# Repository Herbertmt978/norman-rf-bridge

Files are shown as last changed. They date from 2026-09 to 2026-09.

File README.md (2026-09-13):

# Norman RF Bridge

Control Norman Gen1 shutters from Home Assistant using an ESP32 and a small
2.4 GHz radio. Plug it into USB power and leave it near the shutters. Once
set up, it can send commands directly and repeat learned Norman traffic.

The aim is to replace the Norman hub's control role and its USB repeaters with
hardware you can build, update and use with ESPHome. Direct control and radio
forwarding both work on the prototypes. This is still an experimental project,
not a universal plug-in replacement: setup needs watched learning and some commands
still miss panels. Keep the original controls available while testing.

## What it does

**Control shutters from HA.** The companion
[Norman integration](https://github.com/Herbertmt978/Norman-HA-Integration)
adds individual section and whole-room Open/Close controls. HA sends a Wi-Fi
command to the local ESP; the nRF24-compatible module sends the shutter command.
That path doesn't call the Norman hub or need its password. The integration's
RF transport is currently a pre-release feature; follow its
[RF setup guide](https://github.com/Herbertmt978/Norman-HA-Integration/blob/main/docs/esphome-rf.md).

**Work as a USB-powered repeater.** After learning the installation's commands
and enabling relay mode, the board listens for matching traffic and forwards
it automatically. It can forward commands from the Norman hardware or another
ESP bridge. This runs locally, including when Wi-Fi or HA is unavailable.
It isn't an unrestricted repeater for every packet it hears.

**Learn and manage profiles in HA.** Firmware **0.10.2-experimental** uses a
guided flow in the companion integration. Name a section and room, press the
requested controller actions, and confirm what moved. HA can also learn
forwarding-only actions, rename/regroup profiles, and remove a selected profile
with confirmation. Follow the [setup and profile manual](docs/learning.md).
The learner checks repeated matching samples without assuming the hub's codes
advance in order. It tolerates one-off background messages but refuses to guess
between two plausible targets. A fresh board has learned five sections through
the HA wizard using hub commands, without importing profiles or using an SDR.
All five passed watched individual and whole-bedroom Open/Close-upwards tests
after the ESP was placed in the bedroom. Long-term delivery and use in another
household still need qualification.

**Repeat its own commands.** Firmware **0.10.0-experimental** sends up to two
extra full bursts after a direct command, waiting two seconds after each
successful burst finishes before starting the next.
They use the same command bytes and rolling codes, not three different
commands. Each board has an **RF automatic command repeats** switch in HA.
It starts enabled and remembers your choice. Reboots don't replay old commands.

**Stay useful as an ESPHome device.** The image includes an active Bluetooth
proxy, Wi-Fi signal and uptime diagnostics, radio counters, and OTA updates.
Version **0.11.1-experimental** adds last-command and RF-activity ages, transmitter
faults, learning/profile counts, memory and loop timing, plus a three-second
onboard LED Identify button. See [the diagnostic entity guide](docs/diagnostics.md).
You can add supported sensors on spare pins once power and pin conflicts are
checked. The external radio is for Norman RF; it isn't a Wi-Fi adapter or a
general-purpose packet sniffer.

## Where it fits

```text
HA dashboard or automation
        │ Wi-Fi / ESPHome API
        ▼
ESP32 + nRF24 radio ── Norman RF ──► shutters
        │
        └── another commissioned ESP can repeat matching RF

Norman hub / original repeater ── RF ──► ESP repeater ── RF ──► shutters
```

Putting a directly controlled ESP in a distant room can avoid relying on the
hub's radio reaching that room. HA reaches the ESP over Wi-Fi instead. A board
used only as a repeater still needs to hear the upstream transmitter, so its
placement matters.

In the test installation, the existing sunrise/sunset automation now uses the
office and lounge ESP controls. This was an owner-approved move to experimental
daily use, not a claim that every delivery issue has been solved. HA owns the
schedule; the ESP owns the RF transmission and its bounded extra bursts.
Schedules in the Norman phone app must be disabled separately to avoid competing
commands. Removing the hub also means losing its app-based control and schedules.

## Hardware

The prototypes use the same simple assembly:

| Part | Used here |
| --- | --- |
| ESP32 | [Freenove ESP32 board kit](https://www.amazon.co.uk/dp/B0C9THDPXP), ESP32-WROOM-32E, 4 MiB flash, USB-C |
| Radio | [nRF24L01+ PA/LNA module with SMA antenna](https://www.amazon.co.uk/dp/B0DK2Z6C7K); the photographed chip is marked SI24R1, an nRF24-compatible part |
| Antenna | One attached 2.4 GHz antenna per radio |
| Wiring and power | Jumper leads and USB power; the radio takes 3.3 V from the ESP board in these prototypes |
| Enclosure | [Printable base and top](hardware/enclosure/README.md), supplied as STEP files; the owner has printed them and confirmed the fit |

These are the owner's purchase links, not guarantees about future seller stock.
See [hardware and wiring](docs/wiring.md) for the full GPIO map and power advice.
**Never connect the bare radio to 5 V. Fit its antenna before transmitting.**
The PA/LNA supply has not been qualified for a finished product; a stable
dedicated 3.3 V supply and local decoupling are recommended for further testing.

## Will it work with my shutters?

It is a reasonable candidate for another installation using the same Norman
Gen1 radio protocol. It has not yet been qualified in a second home or across
all Norman motor generations. The Norman name alone isn't enough to establish
compatibility, and the HA integration's support for other hub generations
doesn't mean this radio firmware supports them.

Each motorised section needs its own learned command profile. A shutter with
independent upper and lower sections therefore needs two profiles. The sections
share a radio protocol; they don't each require a completely different decoder.
What changes is the command's identity/selector, its supported operation and its
rolling state. The firmware contains the protocol logic, **not this home's
shutter codes**.

**You shouldn't need a Pluto for a compatible installation.** The ESP/nRF24
receiver can log the supported packets from your existing hub or controller.
The remaining job is to associate captures with the panel and direction you
actually operated, validate them, and save them as that panel's profile. This
is handled by the new [HA learning flow](docs/learning.md). A Pluto or
another suitable SDR is useful if your system uses different radio settings,
the logger sees nothing, or the protocol needs further investigation.

Start with [compatibility and learning your shutters](docs/compatibility.md).
Don't copy someone else's frames or an old full-flash backup of a commissioned
board. Matching the protocol is not the same as learning your installation.

## Getting started

1. Assemble the board using the [verified wiring](docs/wiring.md).
2. Run `scripts/test-protocol.ps1`, then `scripts/build-stage1.ps1` using the
   tested ESPHome version, **2026.4.1**.
3. Flash with `scripts/flash-stage1.ps1 -Port COM3`, replacing COM3 with the
   board's actual port. Provision Wi-Fi through USB/Bluetooth Improv or the
   temporary `Norman RF Bridge Setup` access point.
4. Add the discovered ESPHome device in HA. Confirm the radio reports ready.
5. Add the Norman integration's experimental RF transport, select the bridge
   and follow [guided learning](docs/learning.md) for each section or relay action.
6. Select rooms for direct HA control and test their Open/Close while watching.
   Use Reconfigure later to add, rename, regroup or remove profiles.

A new factory image has no learned commands and cannot move or repeat shutters
until commissioned. Once configured, ordinary USB power is enough; a permanent
USB connection to a computer is not required. HA control needs Wi-Fi, local
repeating does not.

The scripts currently use Windows/PowerShell and put build output under
`D:\CodexBuild\norman-rf-bridge`. `scripts/package-experimental.ps1` packages
factory/OTA binaries, source and an ESP Web Tools manifest with checksums.
This is a developer packaging tool, not a hosted one-click installer.
The separate `*-stage0.ps1` scripts are for the older radio-free recovery image,
not normal RF upgrades.

## What has been tested, and what hasn't

The original two boards have moved their local shutters through HA: five office
sections and four lounge panels, individually and as room groups. Learned repeating has
also been observed, including a Wi-Fi-disconnected test. The original Norman
hardware stayed powered during the recent room trials, so those results don't
prove that every RF path used only ESP devices.

A third, freshly commissioned board learned five bedroom sections through HA.
With upward closing selected, each section passed an individual Close/Open
test, and all five passed two whole-bedroom Close/Open cycles on 13 September
2026. These commands used HA's ESP controls without calling the hub. The existing
hub and repeaters remained powered, so they may still have helped carry RF.
The [learning manual](docs/learning.md#fresh-board-testing-and-remaining-limits)
records the capture fixes, closing-direction correction and test limitations.

An earlier automatic-repeat test closed all four lounge panels, but still left
one of five office sections open. A subsequent Open restored both rooms. An
earlier local transmitter fault also remains unexplained. Extra bursts can
recover some misses; they cannot guarantee reception or fix every fault.

HA shows the requested state after the first successful burst. There is no
motor acknowledgement or measured position, so a green HA action is not proof
that a panel moved. Room controls use interleaved individual commands, not a
native whole-room broadcast, and the motors may start at different times.
There are 32 profile slots per bridge and up to eight sections in one room batch.
Stop, arbitrary percentage positioning and battery feedback aren't implemented.

The current bench image has **no API encryption or OTA authentication** and an
open fallback setup AP. Use it only on a trusted local network. Customer-ready
provisioning, longer reliability tests and product/radio compliance are still
work to do before selling it as a finished replacement.

## More detail

- [Commissioning, repeat settings and recovery](docs/commissioning.md)
- [Compatibility and per-panel learning](docs/compatibility.md)
- [Hardware and GPIO wiring](docs/wiring.md)
- [Enclosure CAD files and checksums](hardware/enclosure/README.md)
- [How the firmware works](docs/product-architecture.md)
- [RF captures, test results and known failures](docs/rf-research.md)

## Credits and licence

This project builds on the Norman research and Arduino examples shared in the
[Home Assistant community thread](https://community.home-assistant.io/t/norman-tdbu-blind-control/705405),
including the `NRF24_Sniff` work and Yveaux's NRF24 Sniffer. It is licensed
under [GPL-3.0-or-later](LICENSE). This is an independent project, not an
official Norman product.

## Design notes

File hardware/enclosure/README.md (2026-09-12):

# Prototype enclosure

Owner-supplied STEP originals, added 12 September 2026:

| Part | File | Size |
| --- | --- | ---: |
| Base | [Print Base Final.step](Print%20Base%20Final.step) | 41,938 bytes |
| Top | [Print Top Final.step](Print%20Top%20Final.step) | 14,423 bytes |

These files are small enough to store directly in Git; Git LFS or external
hosting is not needed. Both are STEP AP214 exports with millimetre geometry
units, exported on 11 September 2026. The originals are retained byte-for-byte.

SHA256 checksums:

```text
9be7ac4f990673bee6f19e478c7d4ce23a979b6654de5eac412a7a8af830f098  Print Base Final.step
4fdfd57ec9b67c29abea7e3dbea5255121f62da969045b637946aaa0161d31f8  Print Top Final.step
```

The owner confirmed on12September2026 that the enclosure has been printed,
fit-tested and works with the prototype hardware. This is owner-confirmed
mechanical fit, not an independent electrical, thermal or product certification.

Import these into a STEP-capable CAD application, inspect the dimensions and
export a mesh supported by your slicer. Printer settings, material and fastening
details have not been recorded here; no STL files are supplied yet. Verify fit
for any hardware or printing variation and check electrical clearances and
thermal performance for the intended installation.

Check fit against the actual [board, radio and wiring](../../docs/wiring.md).
Keep the USB connector accessible and both the ESP32 antenna area and the
external 2.4 GHz antenna clear. Avoid pinching jumper wires or leaving exposed
conductors able to short. Fit the radio antenna before powering a transmit-capable
build. An enclosure is not a substitute for a stable 3.3 V radio supply.

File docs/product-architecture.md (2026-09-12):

# Product architecture

## Current implementation: 0.10.0 experimental

Up to32 explicitly commissioned Gen1 section targets per ESP32. Each has its own
exact templates/counter and preferred close direction; all share one SPI radio
owner and global opt-in relay policy.14 targets across3 rooms are commissioned;
physical whole-house acceptance remains distinct from a successful RF burst.

| Owner | Responsibility |
| --- | --- |
| `protocol/` | 30-byte frames, application CRC, rolling permutation, exact learned-command matching, bounded duplicate cache |
| `LearnedPanel` | One193-byte target record per slot: the compatible95-byte command payload, labels and primary-close direction; migration marker and durable sequence reservation |
| `LearnedRelayEndpoint` | Separate79-byte receive-only command/name record per slot; no outgoing counter or motor membership |
| `match_received_command` | One ambiguity-rejecting classifier across both namespaces; only a panel match may update that panel's observed counter |
| `NormanRFMonitor` | Radio detection/readback, receive FIFO, direct bursts, relay timing, watchdog and radio-fault handling |
| `CommandRepeat` | One volatile last-command cache and shared manual/automatic repeat budget; no counter reservation or persisted command queue |
| `LearningSession` | Explicitly owned, receive-only capture with ambiguity checks, distinct presses and expiry; no standalone transmit or persistence authority |
| Profile management | Identity-checked rename/removal; a reusable tombstone stays within the existing record layout, with no global NVS erase |
| ESPHome YAML | Provisioning, HA API, diagnostics, optional Bluetooth and service actions |
| Norman HA RF adapter | Section and room covers using adopted ESPHome services; one shared serializer, bound target identities, no RF encoding/counter ownership/hub fallback |

## Direct control and repeating are different operations

Direct commands select an explicitly learned open, close-down or optional
close-up template. The ESP reserves the next counter in nonvolatile storage,
updates the two rolling bytes and CRC, then sends 100 copies on channel15 at
55ms spacing. A room batch reserves all selected counters before any RF, then
interleaves up to8 targets in each55ms round. An individual command uses that
same path with one target. A storage failure consumes any earlier reservations
without transmission or rewind. Batch failure makes all selected states uncertain.
This copy count follows the locally successful burst test; the
earlier proposed 1–3-copy limit was not established by measurement.

Version 0.10.0 schedules up to two additional unchanged direct-command bursts,
with a two-second gap after each successful completion, within60seconds of the
original start. Version0.9.2 used20-second start intervals.
The ESPHome automatic-repeat switch persists the opt-out setting, default ON;
it does not persist pending commands. A newer command attempt, observed
conflict, changed profile/counter, disable or radio fault cancels pending work.
An active burst is not interrupted. Manual repeats use the same budget.
HA still returns after the first burst; it doesn't provide another retry loop.
See [repeat policy](commissioning.md#automatic-command-repeats).

Repeating does not generate a counter. While enabled, the receiver scans
channels15 and39 at20ms nominal dwell. An exact learned command received on15
is repeated unchanged on39; a command received on39 is repeated on59, with
20 copies at55ms spacing. Channel59 is terminal. The receive FIFO is drained
before retuning so queued frames retain their channel attribution. A
64-entry/60-second exact-frame cache suppresses echoes, including this unit's
direct commands. Live entries are not evicted to admit new traffic; saturation
fails relay closed. Each bridge forwards an exact frame at most once within
the suppression window, even if it later hears that frame on another channel.
An originating bridge suppresses returning copies of its own direct command.
Thus the path is bounded but does not guarantee both hops occur: placement,
receive timing and which channel is heard first matter. Other channels,
unlearned command families and reply packets are not relayed.

Native room endpoints are explicitly learned in a separate32-slot receive
allowlist, using the same protocol command comparison. Only the newly received
30-byte application frame is forwarded; the saved template is never queued
for replay. Room matching ignores only the two sequence bytes and dependent
CRC, not operation/address/selector bytes. It neither observes nor generates
an individual target counter. Panel inventory protocol3 remains unchanged;
the new relay inventory has its own version1 status action.

Both paths use minimum nRF power, an attached antenna, one half-duplex radio,
TX-completion checking and a bounded watchdog. A successful API response means
the RF burst completed, not that the shutter acknowledged or physically moved.

## Boot, persistence and offline operation

Factory defaults have no learned panel and cannot transmit. Once explicitly
commissioned and relay-enabled, USB power restores the profile and repeat
policy after validation, independently of Wi-Fi/HA. Boot itself sends no command.
The HA relay switch uses `restore_mode: DISABLED`; its presentation must not
overwrite the RF owner's saved enabled state during boot.

Configuration/storage failure blocks transmission. Counter reservation is
durable before a direct burst so a reboot cannot reuse a reserved index. Normal
forward observed counter changes are adopted; ambiguous half-range jumps are
ignored. Community three-code resynchronisation is not enabled. Long outages,
counter wrap/coexistence across real controllers and flash endurance still need
extended qualification.

Slot0 imports the deployed95-byte profile once. A durable migration marker
prevents a missing/corrupt new record reviving stale legacy counters. Existing
commissioned slots may be labelled, but cannot silently change identity or reset
their counter/optional endpoint. Other target slots have independent NVS keys.
Relay-only records use disjoint persistent keys and commissioning markers;
they do not migrate, replace or erase panel records. Default empty, invalid
storage fails closed, and a commissioned endpoint cannot silently change its
command identity. The global relay policy has its own persistent owner. Legacy native actions
address slot0 only. Native protocol3 requires explicit slots, fingerprints and
endpoints for each bounded batch. HA owns room membership and one command lock;
the ESP owns batch reservation and RF scheduling. Repeating needs neither HA nor
Wi-Fi. The unreleased sequential HA sender is replaced, not retained as fallback.

## Product B and A* targets

The connected prototype demonstrates learned individual-command repeating
during Wi-Fi loss. UART records native room Open/Close forwarding, but the
watched trial missed one study section; subsequent direct control moved it.
Native room physical reliability and independent RF attribution remain open.
Version0.9 adds reception of direct hub/ESP channel15 traffic and logs confirm
that first-hop forwarding. Exclusive ESP range extension and reliable delivery
without original repeaters are still unqualified. A dedicated
radio-only Product B image, physical commissioning control,
qualified enclosure and production fixture remain future work. Owner-supplied
STEP enclosure designs are stored under hardware/enclosure; the owner confirms
a printed enclosure fits and works. Broader product qualification is still
pending. It is not yet a universal
Norman replacement that can be sold without installation-specific commissioning.

Product A* adds HA control and diagnostics through ESPHome while keeping the
same local repeat policy. Bluetooth proxy remains active; further sensors can
be added using spare GPIOs after checking power, timing and pin conflicts.
It does not provide arbitrary 2.4GHz or Wi-Fi packet decoding.

## Security and release boundary

The current bench image has no API encryption or OTA authentication and an
open Improv/fallback-AP onboarding path. Keep it on a trusted local network;
do not expose it to the internet or distribute it as a secured customer image.
Customer adoption needs unique API/OTA credentials, protected commissioning,
pinned public packages, signed/versioned updates and a recovery policy.

The local experimental package contains source, factory/OTA binaries and hashes,
not Wi-Fi credentials or learned shutter templates. A factory binary is not a
clone of a commissioned device's NVS. Commission each installation separately.

## Evidence and remaining acceptance work

Direct open/down-close and HA-native control were physically confirmed on one
bedroom lower section. Independent Pluto IQ captures match the transmitted
frames. Relay39→59 was observed with Wi-Fi connected and disconnected; stored
relay enable survives reboot. Upward-close has been correlated and learned;
its separate physical replay result belongs in the investigation evidence log.

Remaining work: whole-house physical acceptance, arbitrary position and stop commands,
all-house range, remote-source variations, congested Wi-Fi/Bluetooth coexistence,
extended power-cycle/soak testing, PA/LNA supply qualification, enclosure and
applicable product/radio compliance. No certification or commercial-readiness
claim is made.

See [commissioning](commissioning.md) and [RF evidence](rf-research.md).

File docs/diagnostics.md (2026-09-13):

# Bridge diagnostics in Home Assistant

Firmware 0.11.1-experimental adds read-only diagnostics to each ESPHome device.
The Norman integration's room and panel controls are unchanged. No new hardware
is needed on the documented Freenove ESP32-WROOM board.

## RF activity

- **RF last direct command** describes the last accepted new direct command,
  its first target and how many additional targets were included. Automatic or
  manual identical repeats do not overwrite it. It is not movement confirmation.
- **RF last direct command age** is seconds since that command started.
- **RF last received age** is seconds since any CRC-valid Norman frame arrived,
  including duplicates and unlearned targets. It does not prove a relay path.
- **RF last relay age** is seconds since a relay burst completed successfully.
- **RF pending repeats** counts remaining scheduled extra bursts, not shutters
  awaiting acknowledgement.
- **RF transmitter fault** reports whether the last completed burst failed.
  A later successful burst clears it. **RF last transmitter fault** retains the
  last failure reason until reboot. Hardware readiness remains a separate entity.

Ages use monotonic uptime, so they do not need internet access or time sync.
They are unknown until the relevant event occurs and reset at reboot. Fault
history also resets; no event history is written to flash. HA can record these
entities if longer history is needed. `complete_not_acknowledged` means the
radio completed its burst, not that the motor acknowledged or moved.

## Learning and capacity

**RF learning active**, **RF learning status** and **RF learning samples** expose
the current guided session without its token or raw frames. Samples mean the
strongest candidate's distinct samples (0–2), not approval to save an ambiguous
capture. The wizard remains the authority for accepting and saving profiles.
Once the capture window expires, the diagnostic reports `capture_expired` even
if an earlier acceptance attempt left a cached error such as `need_two_presses`.
This status-priority correction is the only behavior change from 0.11.0.

Saved panels/free panel slots and saved relay profiles/free relay slots are
reported separately: there are 32 slots in each namespace. Only usable saved
profiles count; a storage fault still needs investigation, not blind replacement.

## Board health and identification

**Free memory**, **Minimum free memory** (since boot) and **Loop time** use the
native ESPHome debug component. Loop time is the longest main-loop interval
observed in the reporting period, not CPU utilisation. Existing Wi-Fi signal,
uptime and reset-reason entities remain available.

**Identify board** flashes the onboard GPIO2 LED six times over three seconds,
then leaves it off. Repeated presses during a sequence do not queue more work.
The sequence uses nonblocking ESPHome delays and does not transmit RF. The LED
may not be visible through an opaque enclosure. This mapping is for the
[Freenove ESP32-WROOM board](https://docs.freenove.com/projects/fnk0090/en/latest/fnk0090/codes/C/1_LED.html);
check other boards before using GPIO2 or connecting anything to it.

These diagnostics do not alter RF timings, rolling codes, profile storage,
repeater policy or shutter automations. Keep health polling moderate: the RF
task and existing Bluetooth proxy share a small microcontroller.

## Verification

On 13 September 2026, this build was installed by OTA on three Freenove bridges.
All saved panel identities, names, closing directions and rolling counters
survived the update. HA discovered the new entities and reported the expected
profile counts. A temporary learning session showed active/capturing status,
then returned to idle after cancellation without saving a profile. Identify was
accepted through HA and the radio transmit count stayed unchanged; the LED
itself was not observed through the enclosure.

The 0.11.1 expiry correction was also checked on a real bridge: an empty capture
produced `need_two_presses`, the diagnostic changed to `capture_expired` after
the 60-second window, and cancellation returned it to `idle`. No profile was
saved. Native regression tests cover the expiry boundary with a cached error.

Seven native CTest suites, seven Python tool tests and the pinned ESPHome
2026.4.1 build passed. No shutters were moved for this diagnostics update and no
transmitter fault was deliberately induced. These checks do not extend the
existing RF delivery or whole-house reliability claims.

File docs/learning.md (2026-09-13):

# Set up and manage your shutters in Home Assistant

Use bridge firmware **0.10.2-experimental** with the matching Norman integration
update for this flow. Version 0.10.0 introduced learning but has the hub-capture
limitations described below. Older bridges keep the existing manual
commissioning route. This is for the supported Norman Gen1 RF protocol; a
second household has not yet been qualified. A Pluto SDR is not required when
your controller uses the supported radio settings.

## Install and connect

Fit the radio antenna before powering the board. Follow the [wiring guide](wiring.md),
install the firmware, provision Wi-Fi and add the discovered device to HA's
ESPHome integration. Keep your existing Norman controller working.

Install the matching **Norman 0.5.0b2 candidate** from the
[integration's main branch](https://github.com/Herbertmt978/Norman-HA-Integration/tree/main).
[PR18](https://github.com/Herbertmt978/Norman-HA-Integration/pull/18)
was merged on 12 September 2026. As of 13 September, the normal HACS release is
still v0.4.1 and does not contain this flow.
For a manual candidate install, back up your existing integration folder, copy
main's `custom_components/norman_gen1` directory into HA's
`config/custom_components/norman_gen1`, and restart HA. A subsequent HACS update
can replace a manual candidate, so check the installed version before learning.

In Settings → Devices & services → Add integration, choose Norman, then
**ESPHome RF bridge**. Select the adopted bridge. The profile-management menu
appears even when the board has not learned anything yet.

For a bridge already configured in Norman, use its **Reconfigure** menu. You
do not need ESPHome YAML, packet logs or a terminal for these steps.

## Add a panel

Count independently controlled motors, not window frames. A shutter with
separate upper and lower sections needs two profiles.

1. Choose **Add a motorised section**. Give it a name and room, such as
   `Bottom left` and `Office`. Choose the closing direction you want HA Close
   to use, and whether to learn the opposite closing direction too. Choose
   **Upwards** if that is your blackout position; do not teach a downward
   close while the wizard asks for upward close.
2. Let earlier movements and repeats finish before starting. When the page says
   **Open**, press that individual section's Open action
   twice on the same original controller, at least eight seconds apart. Check
   that the intended section moves, then select Continue within one minute.
3. Follow the Close prompt in the same way. Do not switch between a physical
   remote and the app/hub during a learning session. Their messages may belong
   to different command families. Do not press whole-room controls here.
4. Confirm the physical target and actions, then save. The bridge stores the
   validated templates and current rolling state. Saving itself sends no RF.
5. Add the remaining sections, then choose **Finish: select rooms for HA**.
   Each selected room gets Open/Close, alongside each individual section.
6. Watch the shutters while testing their new HA controls. Successful packet
   transmission is not confirmation of movement. Restore their starting state.

The controller can be the Norman app/hub, a physical remote, or an existing HA
hub control that sends the requested action. Check the actual closing direction:
HA's existing Close button may be configured for the opposite endpoint. A slider
at 100% normally means Open in HA, not the Norman protocol's upward-close value.
Use the Norman app when the existing HA control cannot send the required direction.

For learning, put the ESP where it receives the controller clearly, initially
near the hub if necessary. After saving, move it near the shutters for direct
control and test again. HA reaches it over Wi-Fi; the hub does not have to reach
that room for direct ESP commands. Repeating is different: a relay still has to
hear the upstream radio. A failed distant-room movement is not, by itself,
evidence that learning failed.

Each capture requires two distinct, matching samples at least eight seconds
apart, not repeated copies of one radio burst. Version 0.10.2 remembers sample
codes heard in the first burst so their later echoes cannot count again. It
does not require the hub's decoded codes to advance within a particular range.
The final sample supplies the initial rolling state; this is not a new universal
rolling-code rule or a change to normal transmit-counter handling.

Open establishes the target/controller identity. The bridge keeps up to eight
action candidates and accepts only one with two matching samples. A one-off
message for another target does not spoil the capture. Two qualifying candidates,
conflicting actions for the selected target, or too much distinct traffic cause
rejection rather than a guess. Candidate evidence freezes after its second
sample, but the bridge keeps checking for competing candidates until Continue.
Close then listens only for the accepted Open identity: traffic for another
target supplies no evidence. For a rejected capture, choose Retry and use only
the requested action. A capture lasts one minute and the whole
session expires after ten minutes. Cancel discards unsaved captures. Existing
profiles are never overwritten by learning a duplicate.

While learning, this bridge's direct transmissions, automatic repeats and relay
transmissions pause. Its saved relay/repeat preferences do not change. Other
bridges and Norman hardware continue operating. Reboot discards the learning
session; completed profiles survive. Radio reception must reach the learning
bridge, so initially place it near the original controller.

### Fresh-board testing and remaining limits

On 13 September 2026, a new board was installed and added through HA with no
copied profiles. Teaching it with individual commands from the existing hub
did not complete reliably: capture windows also heard a different valid packet
family, including delayed traffic. Moving the board beside the hub allowed one
Open capture, but did not eliminate the problem. In a separate Close window,
two distinct same-action frames did not satisfy the learner's forward rolling
index check. A later quiet-window retry reached confirmation, but the unsaved
trial was discarded rather than treated as a reliable onboarding pass.

An initial 0.10.1 candidate still rejected background traffic arriving between
the two Open commands. Version 0.10.2 uses the bounded candidate rules above.
Synthetic regression tests cover the observed code jump, background traffic in
either order, competing targets, multi-code burst echoes, wrong panels, conflicting
actions, capacity limits and expiration.

With 0.10.2, all five bedroom sections were saved through the actual HA wizard
using hub commands: all ten Open/Close capture steps completed without retries.
No profiles were imported and no SDR was needed for that learning pass. The five
profiles survived a power cycle and created individual covers plus a room cover.
Some direct movements were unclear from the camera while the ESP was still
beside the distant hub. It was then moved into the bedroom for direct control.

The owner wanted upward closing for blackout. All five profiles were removed
and relearned through the wizard with Upwards selected, using the hub's Open
and upward-close actions. Two capture windows expired while checking the first
replacement; confirming promptly completed it. The other four replacements
accepted both actions on their first capture attempts. This distinction matters:
the ten-step, no-retry result above was the initial downward-close learning pass.

All five upward-close profiles then passed watched individual ESP Close/Open
tests, followed by a second successful whole-bedroom Close/Open cycle. Across
the two room cycles, all five sections closed upwards and reopened; no extra
manual command retry was needed. The final state was open. HA called only the
ESP covers for these movement tests, with the configured two automatic repeats.
The original hub and repeaters remained powered, so this proves direct command
generation without a hub API call, not an exclusively ESP radio path. HA still
has no motor feedback, and these short watched tests do not establish unattended
or whole-house reliability.

This is a fresh-device test in the same installation, not universal hub
compatibility or a qualified second household. Keep the original controller
available and cancel if the intended action cannot be identified consistently.

## Add a repeater action

Choose **Add an action for repeating**. Name a single action, such as `Office
Open`, and press it twice when prompted. Confirm and save it. Repeat separately
for Close and other required actions. You can learn native room actions this
way without pretending that their direct-generation rolling rules are known.

Enable autonomous repeating on confirmation, or later with the ESPHome device's
**RF autonomous relay** switch. A relay-only profile does not create an HA cover.
It forwards fresh matching frames unchanged, locally, even without HA or Wi-Fi.
Use **Finish without direct controls** for a repeater-only bridge.

## Rename, move or remove a profile

Open Norman → Reconfigure → select the bridge → **Rename, regroup or remove a
saved profile**. Choose the named panel or relay action.

Renaming or changing a room keeps the RF identity and rolling state. Existing
HA bindings refresh. Each directly controlled room currently supports up to
eight motorised sections. Changing a room name can change the room entity;
check automations referring to it.

The current edit screen changes names and rooms, not learned endpoints or the
preferred closing direction. To change direction, remove that profile and learn
it again with the desired direction selected. Do this one section at a time;
confirm the replacement works before removing the next. There is no one-click
undo, and references to the previous HA cover may need updating.

Removal requires a separate unchecked confirmation. It affects only that
profile on that bridge. A removed panel loses its bound HA cover, and its room
cover disappears if no bound sections remain. Other bridges, the original hub
and original controllers are not unpaired or erased. Update automations that
used the removed entities. The freed slot can be learned again; recovery is
relearning, not an undo button. Removing a profile from one repeater does not
remove copies from other repeaters.

## Position sliders and delivery limits

Open/Close are supported. The optional opposite endpoint is retained on the
bridge. A continuous percentage slider is not offered: the current encoder
only sends learned endpoints, not arbitrary verified positions. A captured Open
value of 37 is a protocol setting, not a measured 37% opening. A future position
feature needs validated intermediate-position commands; timed movement would
be an estimate and would need a verified Stop command too.

Automatic direct repeats keep the full 100-copy burst, wait two seconds after
successful completion, then repeat it, up to two extra bursts. Frames and
rolling codes are unchanged. New/conflicting commands, disable, faults and
reboot cancel pending repeats; work also expires after 60 seconds. The radio
cannot listen while transmitting. More bursts improve the chance of reception
but do not guarantee that every section moves.

Assign each panel one direct-command bridge. Other bridges can repeat its
traffic; they should not independently generate competing rolling sequences.
Keep schedules in the Norman app separate from HA automations to avoid
conflicting commands.

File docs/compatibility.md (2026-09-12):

# Will it work in another home?

The reusable part is the firmware and radio protocol. The installation-specific
part is the set of commands for your shutters. You can flash the same factory
image onto another board, but it won't arrive knowing which motors to control.

So far, two ESP32/nRF24-compatible boards have been tested in one Norman Gen1
installation. Community work provides further evidence for this protocol family,
but not a compatibility guarantee for every Norman product. A second household
test is still needed before describing setup as generally proven.

## Does each panel use different RF?

Each independently controlled section needs a separate profile. The tested
upper/lower shutter arrangement has more motorised sections than physical
window frames, so count the motors you can control, not just the windows.

The observed sections use the same packet format and radio settings. Their
messages contain different identities/selectors and operations, plus rolling
fields that change between commands. This firmware stores the exact learned
Open and preferred Close templates for each section, with an optional opposite
closing direction. It also stores the sequence needed for the next direct command.

The code understands that format; it doesn't guess another home's addresses.
The capture-to-profile process also establishes which physical panel a command
controls. Neither an RF number nor a label imported from a hub proves where the
panel is mounted.

## Do I need a Pluto SDR?

Not as a normal part of operating the bridge. For the supported radio settings,
the nRF24 receiver can capture decoded packets itself, even before any shutter
profiles have been commissioned. Its private Wi-Fi log includes channel numbers
and payloads marked `RX valid` when the application frame passes validation.

The current receiver uses the community sketch's five-byte radio address,
1 Mbps operation and candidate channels 15, 39 and 59. These are built into the
driver; it isn't a general scanner for unknown addresses or modulation. With
relay enabled it concentrates on channels 15 and 39. A new, uncommissioned unit
does not transmit simply because it heard something.

A Pluto was used here to investigate radio settings and independently compare
transmissions. That research is reusable. You don't need to repeat the entire
SDR investigation for every panel if your packets match the supported format.
If they don't, an SDR may help determine why; buying one is not the first setup
step. No captured packets could also mean poor reception, wiring, power, channel
timing or a different controller source, rather than incompatible shutters.

## Guided setup in Home Assistant

Firmware0.10.0 and the matching Norman integration provide a [guided learning
and profile-management flow](learning.md). It captures actions on the ESP,
requires physical confirmation and creates named panel/room controls. It also
supports relay-only actions and explicit removal. The flow does not decode
unknown radio protocols or infer room membership without user input.

## Advanced manual commissioning

1. Keep a working original controller available. Place the ESP/radio near it,
   with the antenna fitted and reliable power. Leave relay disabled while
   identifying captures.
2. Use the [bounded passive logger](commissioning.md#passive-wi-fi-logs).
   Operate one section and one direction at a time, noting the time and movement.
   Capture Open, the preferred Close direction and any other supported endpoint.
   Keep the source consistent: don't mix an app/hub capture with a different
   remote's frames and assume they belong to the same command family.
3. Validate the frames and their relationship. The log carries a 32-byte radio
   payload; this protocol uses the first 30 bytes as the application frame.
   The last two bytes are padding in the tested implementation. The command-line
   commissioning actions take 60 hex characters for the application frame.
4. Establish the current rolling index using the protocol decoder, not a guessed
   number or a copied value from another home. The byte-25 permutation and
   validation code live in `protocol/`; the hub's two rolling bytes are not
   simply interchangeable. The guided flow handles this for supported captures.
5. Save the panel with `commission-target`, using a stable slot, physical name,
   room, templates and current index. Read `targets` back to check the identity
   and supported endpoints. See the [command reference](commissioning.md#explicit-per-installation-learning).
6. Test that panel in both directions under observation and restore its starting
   state. Only then add more panels and use the integration's room controls.

This advanced route still needs somebody comfortable with logs and command-line
tools. Most supported installations should start with the HA wizard instead.
Neither route automatically authorizes every shutter in radio range.

## Repeating versus replacing the hub

For **repeating**, learn the command families the board is allowed to forward,
then enable its autonomous relay. It forwards a newly heard matching command
without inventing a fresh rolling code. Native room commands need separate
relay-only entries; learning individual sections doesn't automatically permit
every room operation.

For **direct HA control**, learn each motorised section and assign each room to
one direct-command bridge. HA sends Open/Close to that bridge, which creates
the next valid learned command. It can replace the hub's role in those HA
actions without needing the hub reachable over RF. The current whole-room
control is an interleaved batch of individual section commands, not a generated
native room packet.

Use other bridges to repeat those frames, not to independently generate commands
for the same profiles. They could otherwise compete over rolling state. The HA
adapter prevents duplicate direct bindings within one HA instance, but it can't
coordinate independent HA instances or manual native actions elsewhere.

The original hub and app can remain available. Their schedules are not disabled
by adding this integration, and their displayed positions may be stale after
an ESP command. Keep competing schedules off during testing. Long-term
coexistence and missed-command recovery remain areas for further testing.

## Sharing a build

Share the firmware, wiring and enclosure files. Don't share commissioned full
flash images, household captures or saved rolling state. Each installation
needs its own learning and checks, and the current unauthenticated bench image
needs better provisioning before it is suitable for sale.

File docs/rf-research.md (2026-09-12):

# Evidence and current limits

## Camera-observed qualification and ESP-to-ESP forwarding — 12 September 2026

Both prototypes have antennas, USB power and native ESPHome connectivity. One
is positioned by the downstairs hub and one in the office; an unplug/reconnect
test confirmed the mapping. Cameras provide independent
physical observations for the four lounge panels and five motorised office
sections. Home Assistant's assumed state is not used as a movement result.

The leftmost lounge panel closed and reopened through the hub, with the first
bridge logging both unchanged39-to59 relay bursts on0.8. It also closed and
reopened via direct HA-to-ESP commands while both ESP relay policies were off.
Original repeaters remained powered: this proves hub-independent command
generation, not original-repeater-free delivery. All lounge panels were
restored open after these tests.

The old enabled relay listened only on39 while direct ESP commands transmit
on15. Version0.9 adds scanning of15/39 with bounded15-to39 and39-to59 routing,
retaining exact learned allowlists and duplicate suppression. Host route/cache
tests and the pinned ESPHome build pass. Both units retained commissioned
profiles across OTA. The updated first unit logged hub-originated15-to39
forwarding and the lounge pilot still closed/reopened through the hub.

The second unit then sent100 copies of an office Top Left command on15. The
first unit received the matching CRC-valid frame and logged20 unchanged copies
on39. This is positive ESP-to-ESP forwarding evidence, but the office shutter
stayed open. A first-bridge direct Bottom Left test also left that section open.
These initial failures were followed by successful local tests described below;
range, receive-channel availability and counter acceptance are not yet isolated
as causes. A logged relay burst alone is not proof of shutter movement.

All five office motorised sections subsequently passed individual direct
close/open pairs from the office ESP. The whole-office batch closed all five
at11:56:15UTC and reopened all five at11:56:39UTC. The motorless top-right section
is excluded. All four lounge panels also passed individual direct close/open
pairs from the downstairs ESP; the four-panel batch closed all four
at12:01:05UTC and reopened all four at12:01:23UTC. Both rooms were restored open.
The scheduler was unchanged: these room actions interleave learned individual
commands, not a synthesized native-room packet. Camera snapshots confirm end
positions, not exact or simultaneous motor start times.

Two initial office commands failed before a hub close followed by successful
direct open/close/open sequences. Only one of those targets adopted a newer
observed rolling index; another succeeded without adopting the observed index.
This does not establish a universal stale-counter diagnosis or justify automatic
resynchronisation. No counter reset or speculative retry was added.

Direct test pairs called only ESPHome actions, not Norman hub services.
Original hub/repeaters were still powered and could have forwarded those
signals. Each room has one successful combined close/open pass at this
placement, not an isolated ESP-only or long-term reliability qualification.
The owner is retaining the hub and original repeaters for normal operation;
exclusive RF-path isolation is deferred rather than reported as a pass.

Four bounded30-second R1 Pluto recordings captured their intended command
windows but decoded no valid Norman frames. The sample-rate and LO readbacks
were correct. These captures do not independently corroborate RF transmission;
the stronger current evidence is matching frames in the other ESP's receiver
log. The Pluto is upstairs in another office, and its new antenna bands are
not independently identified. All Pluto work remains receive-only.

Native room generation, prolonged room reliability and original-repeater-free
range tests remain separate qualification items. Historical results below retain their
original firmware and placement boundaries.

## Native room receive-only support — 0.8

Three consecutive owner-triggered native study Open requests were captured on
channel39 with valid CRC. They retained the native operation/selector body but
did not follow an increment-by-one sequence under the community byte25 decoder.
Do not infer or generate a room counter from that model. The old0.7.1 firmware
received all three without forwarding because none matched an individual target.

The0.8 build introduces explicitly commissioned receive-only endpoints. It
passes the freshly received application frame unchanged to the existing relay,
without synthesizing either sequence byte. All14 direct target records and
their counters were preserved across OTA; two native study endpoints survive
a subsequent reboot with zero startup transmission. Host tests cover all65,536
sequence-byte pairs, invalid frames, ambiguity, storage failures and counter
isolation.

In the first watched 0.8 native-room close/open trial, UART recorded each fresh
channel39 command matching its separate relay-only endpoint and completing
20 copies on59. No individual target counter changed. The owner reported that
Top Left did not move; the trial is not a full-room physical pass. Subsequent
HA→ESP direct close/open commands moved that section, with ten matching
CRC-valid close frames independently decoded on Pluto channel15.

The native-room Pluto recording ended before the app commands were sent.
Its zero decoded packets are a missed recording window, not evidence of absent
RF. UART completion is firmware evidence, not independent antenna-output
verification. Original repeaters remained powered, so a successful movement
cannot yet be attributed solely to this bridge. Signal, timing and receiver
acceptance remain hypotheses for the miss, not established causes.

A fixed-placement individual Top Left comparison subsequently succeeded for
hub Close/Open with ESP relay disabled. With relay enabled, UART recorded
Close/Open39→59 forwarding,20copies each; the owner confirmed both movements
and all five study sections restored open. Other repeaters
remained powered. The successful disabled baseline means this comparison
cannot establish added range or exclusive ESP contribution.

In a later trial the owner found one original repeater still powered, so the
initial supposed isolation and failed Close are not all-repeaters-off evidence.
After correcting this, clean hub Close/Open with the ESP relay enabled both
physically succeeded while all originals were reported unplugged. UART recorded
20 forwarded copies per command. A matching ESP-disabled Close was then received
on59 with no ESP transmission during the recorded window; the owner reported
that it also closed. This therefore does not establish a range benefit.
A later status read found one additional unrecorded relay burst after the
window ended; do not infer its source or extend the zero-TX interval. Reception
channel alone does not identify the emitter, and a hopping receiver's missing
channel record is not proof of absent RF. This is not yet an extra-range claim.

The subsequent restoration exposed another physical failure: a hub Open with
original repeaters absent did not reopen Top Left, and a later direct ESP Open
also left it closed despite completing100copies/channel15. The originals were
restored by the owner; one normal-hub restoration Open was then issued. This
does not establish whether the miss is range, timing, counter acceptance or
another cause. Do not promote successful TX into reliable movement or reset
rolling state as a speculative recovery.

The production HA study room cover currently reports `level_fanout` for Open
and Close. It is not an equivalent source for an app-native room comparison.
Its existing setting and production integration have not been changed.

## Existing Home Assistant integration

The existing
[`Herbertmt978/Norman-HA-Integration`](https://github.com/Herbertmt978/Norman-HA-Integration)
retains its HTTP hub transport. The experimental RF branch adds a separate
ESPHome-backed cover without moving packet encoding or counter ownership into HA.

## RF evidence

- The Norman HUB01 FCC test report records proprietary 1 Mbps GFSK at 2415,
  2439, and 2459 MHz (nRF channels 15, 39, and 59):
  <https://fcc.report/FCC-ID/PPQ-HUB01/4063103.pdf>.
- The RPT01 filing covers 2415–2459 MHz:
  <https://fccid.io/PPQ-RPT01>.
- Home Assistant community post 58, dated 9 August 2026, provides a working
  Arduino/nRF24L01+ capture-and-replay proof of concept:
  <https://community.home-assistant.io/t/norman-tdbu-blind-control/705405/58>.
- That proof of concept derives from the GPL NRF24 Sniffer:
  <https://github.com/Yveaux/NRF24_Sniffer>.

The reported channel-15 parameters are 1 Mbps, five-byte address
`dc:5c:9c:1c:05`, nRF hardware CRC disabled, and Norman application CRC-16
polynomial `0x0083` with initial value `0xacc8`. The sketch handles a 30-byte
application frame, but its payload-size call is commented out; with the RF24
library's static default it may actually put 32 bytes on air, ending in two
zero pad bytes. Receive-only firmware must retain all 32 bytes until captures
from this installation settle the on-air width.

The shared sketch is not a transparent repeater: it embeds one author's
captured open/close templates, learns/advances a rolling value, and transmits a
100-copy burst. Its AVR pin names, `fdevopen`, ISR behaviour, and device-specific
payloads are not suitable for direct ESP32 deployment.

## What other 2.4 GHz equipment can see

- A stock CC2652P SLZB-06 is a Zigbee/Thread coordinator. Its exposed firmware
  and serial/network protocols do not offer arbitrary proprietary-GFSK capture
  or transmit, and Zigbee's IEEE 802.15.4 PHY does not decode Nordic Enhanced
  ShockBurst. The CC2652P silicon has a flexible proprietary radio mode, but
  using it for Norman would require replacement TI firmware and would take the
  adapter out of ZHA service; this is not a safe experiment on the live
  coordinator.
- UniFi radio capture and Wireshark monitor mode decode IEEE 802.11 frames.
  UniFi can correlate the Norman hub's HTTP calls or show aggregate RF energy,
  but it cannot recover Norman/nRF24 payloads.
- The purchased nRF24L01+ is the appropriate targeted receiver after channel,
  data rate, and address are known. A HackRF-class SDR plus GNU Radio/gr-nordic
  is the better discovery tool when those parameters are unknown.

## Unknowns to resolve on the user's installation

- whether the five-byte address is universal;
- whether the radio payload is 30 bytes or 32 bytes with two pad bytes;
- which channels the Gen 1 plantation shutters use in practice;
- the user's remote/room/panel selectors and command bytes;
- genuine RPT01 forwarding timing, cross-channel behaviour, and loop control;
- whether one half-duplex nRF24L01+ provides adequate relay timing;
- safe rolling-state behaviour across reboot and missed traffic.

## Local RF investigation — 10 September 2026

All 58 posts in the linked community discussion were read, including post39's
no-ACK/repeated-burst observation and the complete post58 Arduino sketch. The
256-entry permutation and reported three-sequential-command resynchronisation
are community findings; resynchronisation is not yet locally proven.

The initial monitor wrote RX_ADDR_P0 in the wrong order. RF24's uint64_t overload
for `0xdc5c9c1c05` writes register bytes `05 1c 9c 5c dc` (least-significant
first). Correcting this produced the first CRC-valid local reception. The
subsequent diagnostic fix drains FIFO occupancy rather than relying on the
cleared RX_DR event and compares only the first 30 bytes for duplicates. The two
extra captured bytes vary and must not be part of application identity.

A Pluto-compatible device identifies as Rev.C Z7010/AD9361. Its R1 connector has
the owner's 2.4 GHz antenna; R2/T1/T2 are unconnected. Receive-only captures use
R1/A_BALANCED, 4 Msps, 3.2 MHz RF bandwidth, manual gain30 dB and int16 I/Q
containers containing signed12-bit samples. The official ADI Windows drivers
were installed manually by the owner; IIO and RNDIS then reported OK.

Independent offline GFSK demodulation at1 Mbps recovered50 CRC-valid copies of
one hub open frame at2415 MHz. Its30 application bytes matched the ESP32 capture
on channel59 exactly. A separate12-second192 MB USB capture recovered73
CRC-valid copies of the corresponding close command, matching the ESP32's
channel39 capture. Open versus close changes application byte4 (`38` versus
`f8`) for this particular hub/panel command, in addition to rolling bytes24/25
and CRC28/29. These are learned installation-specific templates, not universal
open/close opcodes or proof of physical position.

Raw IQ, private templates, command timestamps and hashes are retained outside
Git under `D:/CodexTemp/norman-rf-investigation-20260910`. The first command IQ
recording is explicitly a13.305344-second prefix: native `/tmp` filled before
the requested15 seconds. That prefix transferred with a matching SHA256; it is
usable for frame decoding, not complete-burst counting. Normal host-streamed
captures avoid the native `/tmp` limit and check exact sample count.

`scripts/decode-iq.py` searches clock phase and polarity, accepts only the known
application length and CRC, and does no bit repair. Three deterministic
synthetic waveform/CRC tests and a real idle recording support its validation;
the idle recording contained no CRC-valid Norman frames. The historical0.4
transmit action was bounded to supported channels, valid30-byte frames,1–100
copies,55 ms spacing, lowest nRF power and a10-second cooldown. It is neither
an autonomous repeater nor a sellable release. The current0.5 learned-command
API replaces that raw bench action; see the measurements below.

## Learned commands and autonomous relay — 0.5

The owner physically confirmed native HA→ESPHome→RF close-down/open after reboot.
The profile/counter survive reboot; the relay switch was corrected to stop its
default boot action overwriting the RF owner's saved enabled state.

Independent Pluto reception found84 copies on channel39 while ESP sent only on15.
With the nearby original repeater unplugged, the comparable test decoded zero
on39. The owner restored that repeater; two other repeaters and the hub remained
on throughout, so this does not isolate every path in the house.

For one exact learned command, ESP UART recorded RX39 followed by20 unchanged
TX59 copies and duplicate suppression. A corresponding Pluto59 recording decoded
82 valid copies; other repeaters also transmit there, so not all82 are attributed
to ESP. A second UART test recorded the same relay while Wi-Fi was disabled.
The initial Wi-Fi test did not promptly reconnect; local recovery was then moved
to a script with a bounded restart if reconnection fails. Recovery requalification
is separate from the already observed offline RF operation.

The owner's isolated lower-left upward-close capture decoded61 identical valid
frames. It retains the learned target body but changes bytes2/3 versus close-down,
not byte4 alone. Firmware now accepts only exact saved endpoint bodies, excluding
rolling fields and CRC, instead of treating one byte as a universal command.
The other lower panel differed in the retained target body and is not admitted.

Application counters and the physical effect of newly generated direct commands
are proven for this pilot, not arbitrary controller co-existence over256 cycles.
The 30-byte application identity is established; transmitting32 static bytes
with two zero pads works locally, but this is not a complete on-air format proof
for every Norman product.

## Native room selector investigation — 10 September 2026

Offline comparison of one owner's whole-room open/close pair with five watched
section identities found a consistent selector relationship: reversing the bits
of `section_byte21 XOR room_byte21` gives the section's HA group ID. All five
groups matched the independently read HA metadata. Apart from command and
sequence fields, these frames differ only at byte21. This is evidence for this
room's selector encoding, not a universal address constant, physical membership
guarantee or permission to synthesize arbitrary group commands.

The native room operation also has different command fields from individual
position commands. It must not be implemented by changing only the selector in
an individual template. The captured native pair passes the existing CRC checks,
but its two decoded sequence values were observed about five minutes apart.
They do not establish a next-code rule or independent room-counter ownership.

The [community Arduino sample](https://community.home-assistant.io/t/norman-tdbu-blind-control/705405/58)
uses a byte25 lookup to update one in-memory sequence and generates the next
value for its captured commands. That is not evidence of safe simultaneous
multi-target sequencing or shared hub/remote coexistence on this installation.
Original hub samples do not consistently have byte24 equal to decoded byte25;
do not mistake our generated-frame convention for the original hub's format.

Before 0.8, native room selectors matched none of the14 individual profiles,
so those commands were received but not forwarded. Version0.8 closes that
eligibility gap with separate receive-only endpoints, as described above;
it does not establish a cause or remedy for every missed physical movement.
No generated native-room direct command or room counter has been introduced.

## Later HA room checks and identical repeats — 12 September 2026

The production HA RF candidate exposed nine physically mapped section covers
and two room covers. Separate room close/open checks passed again, but subsequent
combined and sequential-room runs missed sections. In the sequential run, with
a five-second gap after the office burst, HA completed both actions while the
cameras showed office4/5 and lounge2/4 closed. Open restored the lounge but left
two office sections closed; individual Opens restored them. The schedule was
not migrated or enabled. The HA position is still an assumed command intent.

At the owner's request,0.9.1 adds explicit repeats of the most recent completed
local command. These are separate100-copy bursts using the original frames,
not repeated new rolling-code reservations. Maximum two additional bursts
within60seconds, exact request matching, volatile storage and invalidation
rules are documented in [commissioning](commissioning.md#explicit-identical-command-repeat).
Default sending and autonomous relay policy are unchanged.

Both prototypes received0.9.1; all14 identities/endpoints were retained. Office
rolling counters were identical across its update; downstairs office counters
advanced while it received the ongoing office test, with no reset. Five host
CTest suites, three decoder tests, four logger tests and the pinned ESPHome
build passed. Fresh boot rejected repeat without a prior local command.

Camera-observed comparison:

| Trial | Original burst | Later identical burst(s) | Restoration |
| --- | --- | --- | --- |
| Office Close | Four of five closed; Top Left remained open | First repeat still4/5; second repeat5/5 | New Open reopened5/5; an extra identical Open did not reverse them |
| Office second pair | Close5/5 on first burst | One identical Close retained5/5 | Open5/5 on first burst |
| Lounge Close | Three of four closed; third from camera-left stayed open | First identical repeat4/4; second retained4/4 | New Open reopened4/4 |

Originals and repeats were about20seconds apart in these manual comparisons.
The office log recorded500,1000,1500 total transmitted copies across its first
Close and two repeats. Native counter readback showed only the original
reservation. A further repeat request was refused. Lounge repeats likewise
left the four command counters unchanged. These results demonstrate recovery
from specific misses, not a generally validated automatic retry cadence.

During the first office comparison, the downstairs bridge, still running0.9,
logged `radio_tx_failed` partway through a channel39 relay. The latched fault
disabled autonomous repeating. Its subsequent0.9.1 OTA/reboot restored the
saved enabled policy. The existing diagnostic does not distinguish a timing,
SPI, supply or radio fault; no root cause or permanent fix is claimed. Remote
shutter range alone cannot explain the local transmitter-completion failure,
because this sender has automatic acknowledgements disabled. Investigate this
fault before relying on unattended schedules or claiming a finished repeater.

Original hub/repeaters remained powered throughout. Exact-copy replays can be
suppressed by other bridges' duplicate caches; these tests do not prove every
RF hop repeats again. All tested shutters were returned open. Raw captures,
household images and installation identities remain outside the public repo.

## Automatic bursts and direct HA schedules — 12 September 2026

The owner requested that the later identical bursts happen on the ESP without
manual intervention. Firmware 0.9.2 uses the existing cache and radio scheduler:
two extra bursts at least 20 seconds apart, expiring 60 seconds after the
original start. A separate persistent HA switch defaults ON. Only that policy
is persisted, never the pending command. The manual action shares the budget.
No additional rolling counter is reserved for a repeat. Cancellation and
fault behaviour are described in [commissioning](commissioning.md#automatic-command-repeats).

Both prototypes received the same pinned ESPHome 2026.4.1 build. Native reads
before and after OTA showed all 14 target records, including their counters,
unchanged on each. Both booted ready, relay enabled, automatic policy ON and
zero pending/started automatic bursts.

One HA Close was sent to each local room cover, with no manual repeat action:

| Room | Early camera observation | After both automatic bursts | New Open |
| --- | --- | --- | --- |
| Office | Four of five closed; Bottom Left stayed open | Still four of five closed | All five open |
| Lounge | Three of four closed; second from camera-left stayed open | All four closed | All four open |

Each board logged exactly two automatic bursts about 20 seconds apart. Both
Open commands also completed their automatic budgets. No transmitter fault
was logged during these bounded recordings, but this is not a diagnosis or
fix for the earlier fault. This run recovered a lounge miss and did not
recover the office miss. The original hub and repeaters remained powered.

The office opt-out test sent another Open, then disabled automatic repeats
before its due time. Pending work cleared and the started-repeat count did
not increase. After the preference had time to save, a reboot retained OFF
with no cached command. Re-enabling did not revive it; the policy was returned
to ON for normal use. The unit tests cover expiry, busy-radio deferral,
counter/profile conflicts, shared manual budget and clock wrap.

The owner also explicitly requested moving sunrise/sunset off hold. The
existing HA automation now uses local office/lounge RF room controls and is
enabled, with the same sun triggers and a five-second gap after the office
action. Both branches passed isolated HA execution tests with fake cover
services on the pinned and cached-latest test environments; the saved live
configuration and enabled state were then read back. The physical tests above
exercise the real covers, not a naturally occurring sunrise or sunset.
The prior automation is backed up; phone-app schedules were not changed.
This is experimental daily use at the owner's request, not a new claim of
reliable unattended or isolated ESP-only operation.

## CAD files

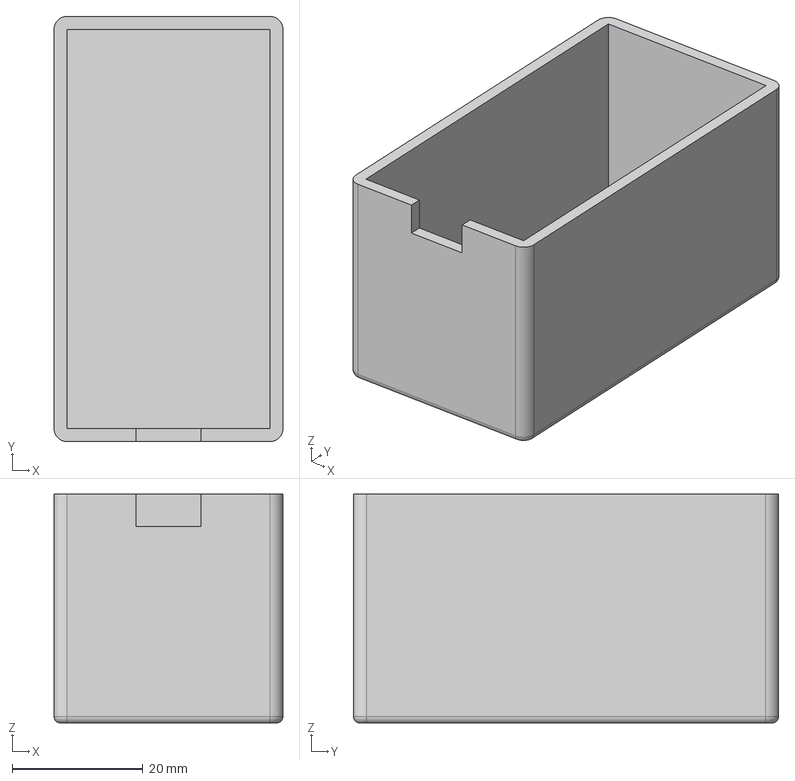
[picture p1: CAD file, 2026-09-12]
hardware/enclosure/Print Base Final.step
35.0 x 65.0 x 35.0 mm

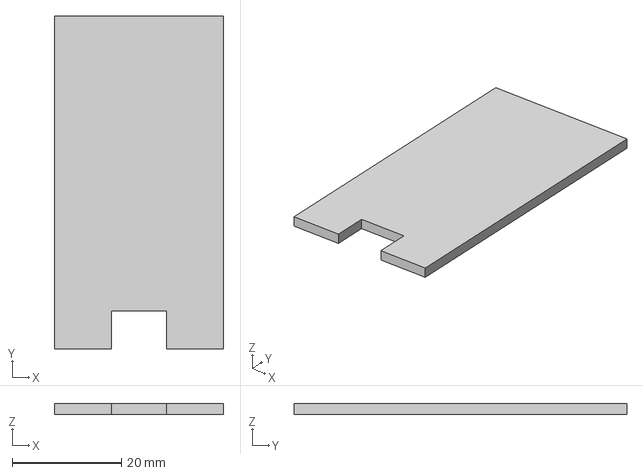
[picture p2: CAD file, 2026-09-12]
hardware/enclosure/Print Top Final.step
31.0 x 61.0 x 2.00 mm

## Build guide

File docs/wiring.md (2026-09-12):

# Hardware and verified wiring

This repository owns the bridge firmware, hardware description, wiring and
installation tools. The separate Norman HA integration consumes its ESPHome API.

## Tested prototype

| Part | Observed hardware and qualification boundary |
| --- | --- |
| Controller | Freenove ESP32 development board, ESP32-WROOM-32E shield,4MiB flash, USB-C power/data |
| Radio | SMA-antenna PA/LNA module sold as nRF24L01+; photographed radio IC is marked SI24R1. Describe it as nRF24-compatible, not verified genuine Nordic silicon. |
| Antenna | Attached2.4GHz SMA antenna on the radio module |
| Connections | Jumper-wire SPI prototype using the pin map below; no custom production PCB |
| Power | USB powers the ESP32 board. The radio requires regulated3.3V and common ground; this prototype has not qualified a production PA/LNA supply. |

Both prototypes have been tested with their own antennas. Results do not qualify
another module vendor, antenna gain or supply. Keep installation
identifiers and private commissioning captures outside this source repository.

## Parts used in the prototype

The owner supplied these purchase links for the actual build (not affiliate
links or a guarantee of current seller specifications):

- [Freenove ESP32 board kit, ASIN B0C9THDPXP](https://www.amazon.co.uk/dp/B0C9THDPXP).
- [PA/LNA radio purchase, ASIN B0DK2Z6C7K](https://www.amazon.co.uk/dp/B0DK2Z6C7K).

The assembled prototype uses the ESP32 board, radio with its 2.4 GHz antenna,
jumper leads and USB power. No additional regulator/capacitor assembly was
reported fitted. The power improvements below are recommendations for further
qualification, not claims about parts already installed. The Amazon pages could
not be independently retrieved during publication; the supplied order photos
and board markings are the hardware evidence. Seller substitutions are possible.

## Pin map

This mapping is verified by read-only SPI register access and is used by the
Stage 1 monitor firmware. Stage 0 remains a radio-free rollback image.

| nRF24L01+ pin | ESP32 connection | Notes |
|---|---|---|
| GND | Common ground | Join ESP32 and external regulator grounds. |
| VCC | Clean regulated 3.3 V | Never connect the bare module to 5 V. |
| CE | GPIO4 | Tested monitor enable. GPIO4 is strap-sampled at reset but does not select a supported ESP32 boot mode. |
| CSN | GPIO5 | Tested SPI chip-select. GPIO5 is strap-sampled at reset; retain the nRF24 input-only connection and prove cold boot/flash reliability before product use. |
| SCK | GPIO18 | ESP32 VSPI clock. |
| MOSI | GPIO23 | ESP32 VSPI controller-to-radio data. |
| MISO | GPIO19 | ESP32 VSPI radio-to-controller data. |
| IRQ | GPIO27 | Reserved; current firmware polls the RX FIFO and does not use IRQ. |

The PA/LNA board can draw sharp current peaks. Use a dedicated, stable 3.3 V
regulator and place 100 nF ceramic plus 47–100 µF bulk capacitance at the radio
connector. Attach the SMA antenna before any transmit-capable firmware is used.

The owner-supplied [enclosure STEP files](../hardware/enclosure/README.md) are
stored in this repository. The owner confirms the printed enclosure fits and
works with the prototype. Print settings, electrical clearances and thermal
performance are not separately documented or qualified.

The mapping assumes the module shield reads `ESP32-WROOM-32E`. Recheck that
marking before wiring; ESP32-WROVER boards use some pins for PSRAM.

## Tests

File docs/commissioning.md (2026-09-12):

# Experimental commissioning

## Build and install

Use the tested ESPHome2026.4.1 and the Freenove ESP32-WROOM/4MiB hardware in
[wiring](wiring.md). The PA/LNA module needs an attached antenna and a stable
3.3V supply; never apply5V directly to the radio.

1. Run `scripts/test-protocol.ps1` and `scripts/build-stage1.ps1`.
2. Flash a new board with `scripts/flash-stage1.ps1 -Port <verified-COM-port>`.
   Despite their historical names, these two scripts now build/install the
   current experimental RF image, not the old receive-only baseline.
3. Provision Wi-Fi with USB/Bluetooth Improv or the temporary fallback AP and
   adopt the discovered ESPHome device in HA. Complete this on a trusted LAN.
4. Verify radio-ready diagnostics. An uncommissioned profile must remain
   unavailable for direct control and relay.
5. Capture each section's open and preferred close commands with the original app/hub,
   keeping raw captures private. Confirm physical action, CRC and target matching.

Builds and packages stay under `D:/CodexBuild/norman-rf-bridge`, outside Git.
`scripts/package-experimental.ps1 -AllowDirty` makes a labelled development
bundle with a source archive and file hashes. Omitting `-AllowDirty` requires a
clean checkout. A local bundle does not publish a GitHub release.

## Explicit per-installation learning

Use `scripts/bridge-control.py --host <IP> --expected-name <ESPHome-name>` with
one operation below. Inputs are captured60-character application-frame hex,
not example commands from someone else's installation.

| Operation | Additional arguments | Effect |
| --- | --- | --- |
| `targets` | none | Read inventory, slots, fingerprints and capabilities |
| `commission-target` | `--slot`, `--name`, `--room`, `--open-frame`, `--close-frame`, `--last-index`, `--open-position`, `--close-position` | Persist a target in slot0–31; preferred close is0 or100 |
| `learn-target-endpoint` | `--slot`, `--position`, `--frame` | Save a physically correlated opposite closing template |
| `target-command` | `--slot`, `--profile-id`, `--position` | Identity-checked command for a learned endpoint; automatic repeat policy applies |
| `relay` | `--enabled on` or `off` | Persist the local autonomous repeat policy |
| `relay-endpoints` | none | Read the separate receive-only allowlist and relay counters |
| `learn-relay-endpoint` | `--slot`, `--name`, `--frame` | Persist one receive-only command endpoint; never transmits the supplied frame |

### Native room repeating (0.8 experimental)

Native room commands are not individual section targets. Learn each captured
room operation in the separate relay-only namespace using `learn-relay-endpoint`.
It has32 independent slots and is not returned by `targets`, so it cannot create
a motor cover, enter room fan-out or reserve an outgoing rolling code.

An entry matches only the exact CRC-valid learned30-byte application command,
allowing variation in bytes24/25 and their dependent CRC. Only a newly received
matching frame may be forwarded unchanged through the existing39-to59 relay.
The saved frame is a matching template, not a replay queue. Learning alone never
transmits. Other room operations, selectors, replies and unlearned families are
not granted permission. Existing endpoint identity cannot silently be replaced.

The same opt-in relay switch, duplicate cache and fault policy apply. Native
room support still needs physical and independent RF qualification on each
installation; accepting a template is not proof of room-wide movement.

Keep slots stable. Each target owns its counter and exact endpoint templates.
Names and room labels are printable ASCII, at most47 characters. Matching room
labels create room covers in HA. Recommissioning an existing matching target
updates labels without rewinding its counter or deleting its optional endpoint.
Duplicate families in different slots are rejected. Do not recover corrupt
rolling state by erasing NVS or restoring a stale full-flash backup.

Legacy `status`, `commission`, `command` and `learn-close-up` operate on slot0
only for existing native callers; they are never whole-room broadcasts.

### Verify physical names before HA discovery

An imported hub label is not proof of physical location. From a known starting
state, operate one identity-checked slot, ask which section moved, then restore
that same slot and confirm it. Record the observed location with its slot and
fingerprint. Do not infer the final location by elimination or use assumed HA
cover states as motor feedback.

For an already commissioned matching slot, `commission-target` can save its
confirmed display name using the same captured frames, room and endpoints.
Read the live inventory first and supply its current index; existing matching
slots retain their stored counter and optional endpoint. This is a metadata
operation, not a movement command. Keep the original captures unchanged.
Read back all targets and verify that only the intended names changed, with
fingerprints, counters, rooms, endpoint capabilities and relay policy retained.
Stop on any mismatch; do not restore old rolling state as a rollback.

The Norman RF integration imports these names during setup. For an existing RF
entry, use **Reconfigure** on that same bridge to refresh its saved metadata.
Display names are not polled into the bound entry automatically. Section unique
IDs are slot-based, not name-based; keep slots fixed. A room label is also a
grouping input, so a room reassignment is not merely a panel display-name edit.
Existing hub entries are separate and are not renamed by changing ESP metadata.

Firmware0.7 native protocol3 adds `rf_targets_command(targets_json)`. Its JSON
object has equal-length arrays `slots`, `positions`, `profile_ids`, with1–8
unique targets. Every identity/endpoint is checked and every counter is durably
reserved before the first RF packet. The single scheduler sends each target
once per55ms round, for100 copies each. Any failure leaves all selected physical
states uncertain. HA does not retry the action. Firmware 0.10.0 can schedule
additional identical bursts after successful local transmission, as described below;
a transmitter failure cancels them.

The optional encrypted-API key is read only from `ESPHOME_NOISE_PSK`. The current
bench image is unencrypted; this option supports a later owner-secured build.

For the locally tested section raw open is37, close-down0 and close-up100.
These are not HA percentages: HA's RF cover exposes open/close only, not a
position slider. Do not extrapolate these values to another motor or blind type.
The upward-close capture changes bytes2/3 as well as its difference from open
at byte4. Runtime matching compares the entire learned command body excluding
only rolling fields and the recalculated CRC, not a guessed universal opcode.

## Verify each commissioned unit

- Physically observe each supported direction, then restore the starting state.
- Reboot and verify the saved panel, counter and relay-enabled state; boot must
  not emit a movement command.
- Confirm source channel15 produces one bounded unchanged channel39 relay and
  source channel39 produces a channel59 relay. Confirm echoes and channel59
  inputs are not forwarded. Measure each placement; do not claim an all-house
  test from one received frame or one successful movement.
- Disconnect Wi-Fi temporarily and confirm local repeating continues. The
  commissioning `rf_test_wifi_pause` action pauses Wi-Fi30seconds, then enables
  it; a local recovery script restarts after another45seconds if still offline.
- Verify HA/API recovery, Bluetooth availability, power integrity and fault
  diagnostics before leaving a unit unattended.

## Home Assistant Norman RF transport

The candidate in `Herbertmt978/Norman-HA-Integration` adds **ESPHome RF bridge
(experimental)** as a separate setup choice. Adopt ESPHome first, then select
its commissioned bridge. It creates section and room covers using each target's
preferred closing direction. A room can contain up to8 interleaved targets.
This needs neither hub credentials
nor a hub fallback. Existing hub covers remain separate and may show stale
assumed states after direct RF movement.

The bridge owns counters/templates; HA pins target slots, fingerprints, room
membership and endpoints. Changed commissioning or a missing bridge makes
affected covers unavailable. Reconfigure deliberately refreshes those bindings.
State is unknown on startup and explicitly assumed after a completed RF burst.
There is no physical position or battery feedback through this RF transport.

## Recovery and limits

### Automatic command repeats

Firmware **0.10.0-experimental** changes automatic repeats to a two-second
quiet gap after each completed burst. Version0.9.2 used20-second start intervals.
The **RF automatic command repeats** switch on each ESPHome device defaults
to ON. It is separate from **RF autonomous relay**, which controls forwarding
received traffic. Either switch can be used without the other.

After a successful local command, the ESP can send up to two more identical
bursts, waiting two seconds after each successful burst finishes. Each
burst retains the existing 100 copies per target and 55 ms round cadence.
The extra bursts reuse the original application bytes and rolling indices;
they don't reserve more counters or write the command back to flash.

The radio must be idle and the previous direct burst must have completed.
Busy periods defer the next attempt, but the whole budget expires 60 seconds
after the original start. There is no endless retry loop. Manual repeats share
the same two-attempt budget; the next automatic attempt waits two seconds after
the manual burst finishes.

A newer local command attempt cancels the old pending repeats, even if that
new attempt is rejected as busy. An already-running burst finishes normally;
it is not preempted, so a new HA command during that roughly six-second burst
may need to be sent again after completion. Reconfiguration, a changed learned
identity/counter, or an observed conflicting command also invalidates the cache.
The ESP cannot cancel in response to an external command it never receives.

Turning the automatic-repeat switch OFF clears pending repeats. Turning it
back ON also clears the shared cache, including any manual-repeat allowance
created by a command sent while automatic repeats were OFF. Only future
commands get automatic repeats. The setting uses normal ESPHome preference
storage and survives reboot once saved; allow the preference flush interval
before removing power. Cached commands never survive reboot. Startup alone
therefore cannot move a shutter.

Radio faults cancel pending repeats and leave the existing fault protection
in place. This update does not automatically rearm a failed radio or claim to
fix the earlier unexplained transmitter fault. Inspect the RF diagnostics.
The native `rf_targets_status` response also reports `automatic_repeats`,
`repeats_remaining` and `automatic_repeat_count` (started automatic bursts
since boot). The HA command still responds after the first burst; it doesn't
wait for the later bursts or obtain motor feedback.

The office/lounge sunrise/sunset automation in the test installation now uses
the local ESP room covers, at the owner's request. Its original sun triggers
are retained, with the lounge action five seconds after the office action
completes. That gap isn't a demonstrated reception fix. The earlier hub-based
configuration is backed up, and phone-app schedules were not changed.
Other installations must use their own verified cover IDs and schedule choices.

### Explicit identical-command repeat

Firmware0.9.1 adds `rf_targets_repeat`, a manual diagnostic action with the same
`targets_json` shape as `rf_targets_command`. Supply the identical slots, order,
positions and profile IDs from the most recent completed local command. A repeat
sends the same30-byte application frames plus the same two padding bytes on
channel15,100copies per target at the existing55ms round cadence. It does not
reserve or advance any rolling index. The first command already sends100copies;
this action tests a later additional burst, not a previously absent copy loop.

At most two repeats are allowed within60seconds of the original burst starting.
The radio must be idle and the previous command must have completed. A new local
command, reconfiguration, radio failure, changed profile/counter or conflicting
observed command invalidates eligibility. Reboot clears the cache. Incoming RF
can invalidate the cache but cannot create repeat authority. An unseen external
command cannot be detected, so test promptly with other controls idle.

For one target originally sent on its own:

```powershell
python scripts/bridge-control.py --host BRIDGE_IP --expected-name BRIDGE_NAME repeat-target --slot SLOT --profile-id PROFILE_ID --position POSITION
```

Do not retry a stale command or run an unbounded loop. Identical duplicates may
be ignored by a motor that already accepted them, and may still fail if that
code is unacceptable. Autonomous relay retains its exact-frame duplicate cache:
a repeated local packet is not promised another forwarding burst at every bridge.
Observe actual movement and restore the starting state. HA room covers do not
automatically call this action; firmware 0.10.0 owns the background repeat policy
above. Long-term unattended delivery remains unqualified, despite the owner's
decision to begin using the direct ESP schedules.

### Passive Wi-Fi logs

USB power alone is sufficient once Wi-Fi has been provisioned. For a bounded
read-only log recording, without sending a radio or movement action:

```powershell
python scripts/bridge-log.py --host BRIDGE_IP --expected-name BRIDGE_NAME --seconds 60 --output D:\PrivateCaptures\bridge.jsonl
```

Create the private destination directory first. The file must not already
exist. Logs are timestamped at the PC and may contain installation-specific
RF frames; do not commit them. The default cap is16MiB; recordings are limited
to one hour and64MiB. The tool disconnects when its duration or byte cap is
reached. A quiet log is not proof that no RF was present: radio tuning, reception
and firmware log budgets also affect visibility.

Both prototypes were updated to0.9 on12September with their14 target identities
and two native-room receive endpoints retained. Both have their own antennas
and relay enabled. This supersedes the earlier antenna-loan state below.

`esphome/stage0-recovery.yaml` and the `*-stage0.ps1` build/flash/OTA scripts use
the original radio-free0.2.0-stage0 image. They do not accidentally build the
current RF YAML. Recovery does not erase stored NVS; returning to an RF image
can restore its commissioned policy. Disable relay explicitly before ordinary
maintenance where that is required.

The old `scripts/esphome-rf-test.py` is historical0.4 bench tooling; its raw
transmit API is absent from current firmware. Use the learned-command controller.
The second prototype was updated on 10 September 2026 to the same 0.8 image,
then commissioned with an attached test antenna: 14 profiles, the pilot's extra
closing direction and two native-room relay endpoints. Relay policy and profiles
survive reboot; fresh over-the-air qualification remains pending. The first
bridge's relay was disabled while its antenna was loaned to the second.
There are32 target
slots and14 commissioned sections across3 rooms in the current installation.
Only the original pilot has both closing directions learned; other sections
currently support their preferred close only. Capacity is not physical range
evidence. See the security, coexistence and commercial gaps in
[product architecture](product-architecture.md).

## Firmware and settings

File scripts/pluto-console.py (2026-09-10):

"""Bounded receive captures using an already logged-in Pluto USB console.

Uses the device's native iio_readdev. No network driver, radio TX, or device
firmware change is needed. IQ files remain under /tmp and transfer with SHA256
verification. The USB CDC channel does not use a physical 115200-baud UART.
"""

import argparse
import base64
import hashlib
import json
import os
from pathlib import Path
import re
import time
import uuid

import serial


class Console:
    def __init__(self, port):
        self.serial = serial.Serial(port, 115200, timeout=0.2, write_timeout=5)
        self.serial.write(b'\x03\r\n')
        greeting = self.prompt()
        if b'Password:' in greeting:
            self.serial.write(b'\x03\r\n')
            greeting = self.prompt()
        if b'login:' in greeting:
            password = os.environ.get('PLUTO_CONSOLE_PASSWORD')
            if password is None:
                raise RuntimeError('Set PLUTO_CONSOLE_PASSWORD for console login')
            self.serial.write(b'root\n')
            if b'Password:' not in self.prompt():
                raise RuntimeError('Console did not request login password')
            self.serial.write(password.encode() + b'\n')
            if b'# ' not in self.prompt():
                raise RuntimeError('Console authentication failed')
        self.serial.write(b'stty sane -echo clocal -hupcl\n')
        self.prompt()

    def prompt(self):
        data = bytearray()
        until = time.monotonic() + 6
        while time.monotonic() < until:
            data.extend(self.serial.read(4096))
            if any(value in data for value in (b'login:', b'Password:', b'# ')):
                return bytes(data)
        raise TimeoutError('Console did not produce a login or shell prompt')

    def close(self):
        self.serial.close()

    def command(self, command, timeout=10):
        marker = "END_" + uuid.uuid4().hex
        self.serial.reset_input_buffer()
        self.serial.write((command + "; printf '\\n" + marker + ":%s\\n' $?\n").encode())
        data = bytearray()
        until = time.monotonic() + timeout
        pattern = re.compile(rb"\r?\n" + marker.encode() + rb":(\d+)\r*\n")
        while time.monotonic() < until:
            data.extend(self.serial.read(65536))
            match = pattern.search(data)
            if match:
                output = data[:match.start()].decode(errors="replace").strip()
                if int(match[1]):
                    raise RuntimeError(output)
                return output
        raise TimeoutError("Pluto console command timed out: " + repr(bytes(data[-1000:])))

    def download(self, remote, destination, size):
        # The console's raw binary path loses USB blocks on this Pluto/Windows
        # combination. POSIX uuencode -m provides an ASCII envelope; validate
        # framing, decoded length and the device's SHA256 before accepting IQ.
        end = ("END_" + uuid.uuid4().hex).encode()
        self.serial.reset_input_buffer()
        self.serial.write((f"uuencode -m {remote} capture; printf '\\n"
                           + end.decode() + "\\n'\n").encode())
        count = 0
        digest = hashlib.sha256()
        started = last_progress = time.monotonic()
        until = started + 20
        pending = b""
        header_seen = finished = False
        with destination.open("xb") as output:
            while not finished:
                chunk = self.serial.read(65536)
                if chunk:
                    until = time.monotonic() + 20
                    lines = (pending + chunk).split(b'\n')
                    pending = lines.pop()
                    for line in lines:
                        line = line.strip()
                        if not line:
                            continue
                        if line.startswith(b'begin-base64 '):
                            header_seen = True
                        elif line == b'====':
                            pass
                        elif line == end:
                            finished = True
                            break
                        elif header_seen:
                            payload = base64.b64decode(line, validate=True)
                            output.write(payload)
                            digest.update(payload)
                            count += len(payload)
                            if count > size:
                                raise RuntimeError('Transfer exceeds expected capture size')
                if time.monotonic() > until:
                    raise TimeoutError(f"Transfer stalled at {count}/{size}")
                if time.monotonic() - last_progress > 5:
                    print(json.dumps({"bytes": count, "total": size}), flush=True)
                    last_progress = time.monotonic()
        if count != size:
            raise RuntimeError(f'Transfer length mismatch: {count}/{size}')
        return digest.hexdigest(), time.monotonic() - started


def main():
    parser = argparse.ArgumentParser(description=__doc__)
    parser.add_argument("--port", default="COM5")
    sub = parser.add_subparsers(dest="action", required=True)
    sub.add_parser("info")
    capture = sub.add_parser("capture")
    capture.add_argument("label")
    capture.add_argument("--frequency", type=int, default=2415000000)
    capture.add_argument("--rate", type=int, default=4000000)
    capture.add_argument("--seconds", type=float, default=5)
    capture.add_argument("--gain", type=int, default=30)
    capture.add_argument("--download", type=Path)
    download = sub.add_parser("download")
    download.add_argument("label")
    download.add_argument("destination", type=Path)
    args = parser.parse_args()
    if args.action != "info" and not re.fullmatch(r"[a-zA-Z0-9_-]{1,60}", args.label):
        parser.error("Label must be 1-60 letters, digits, underscores or hyphens")
    console = Console(args.port)
    try:
        if args.action == "info":
            print(console.command("cat /sys/bus/iio/devices/iio:device0/name; "
                  "iio_attr -q -i -c ad9361-phy voltage0 sampling_frequency; "
                  "iio_attr -q -i -c ad9361-phy voltage0 rf_bandwidth; "
                  "iio_attr -q -i -c ad9361-phy voltage0 gain_control_mode; "
                  "iio_attr -q -i -c ad9361-phy voltage0 hardwaregain; "
                  "iio_attr -q -c ad9361-phy altvoltage0 frequency; free -m"))
        elif args.action == "capture":
            if not (2400000000 <= args.frequency <= 2483500000 and
                    2000000 <= args.rate <= 8000000 and 0 < args.seconds <= 15 and
                    0 <= args.gain <= 70):
                parser.error("Capture settings outside the bounded 2.4 GHz RX range")
            count = int(args.rate * args.seconds)
            if count * 4 > 240000000:
                parser.error("Capture exceeds the 240 MB device memory budget")
            base = "/tmp/norman-" + args.label
            settings = [
                f"test ! -e {base}.iq",
                "task_free=$(df -k /tmp | tail -1 | awk '{print $4}'); "
                f"test \"$task_free\" -gt {(count * 4 + 8388608) // 1024}",
                f"iio_attr -q -i -c ad9361-phy voltage0 rf_port_select A_BALANCED",
                f"iio_attr -q -i -c ad9361-phy voltage0 gain_control_mode manual",
                f"iio_attr -q -i -c ad9361-phy voltage0 hardwaregain {args.gain}",
                f"iio_attr -q -i -c ad9361-phy voltage0 sampling_frequency {args.rate}",
                f"iio_attr -q -i -c ad9361-phy voltage0 rf_bandwidth {int(args.rate * .8)}",
                f"iio_attr -q -c ad9361-phy altvoltage0 frequency {args.frequency}",
            ]
            print(console.command(" && ".join(settings)))
            print(json.dumps({"label": args.label, "frequency": args.frequency,
                              "sample_rate": args.rate, "samples": count,
                              "gain_db": args.gain, "host_time": time.time(),
                              "format": "ci16_le; signed 12-bit I/Q in 16-bit containers"}), flush=True)
            job = (f"iio_readdev -u local: -b 262144 -s {count} cf-ad9361-lpc voltage0 voltage1 "
                   f">{base}.iq 2>{base}.err; task_rc=$?; echo $task_rc >{base}.status; "
                   f"test $task_rc -eq 0")
            print(console.command(job, timeout=args.seconds + 20), flush=True)
            if args.download:
                args.destination = args.download
        if args.action == "download" or (args.action == "capture" and args.download):
            remote = "/tmp/norman-" + args.label + ".iq"
            base = remote[:-3]
            print(console.command(f"test \"$(cat {base}.status)\" = 0 && cat {base}.err"))
            listing = console.command(f"wc -c <{remote}; sha256sum {remote}", timeout=60)
            numbers = re.findall(r"(?m)^\s*(\d+)\s*\r?$", listing)
            hashes = re.findall(r"\b[a-f0-9]{64}\b", listing)
            if len(numbers) != 1 or len(hashes) != 1:
                raise RuntimeError("Could not parse capture size/hash")
            size = int(numbers[0])
            if not 0 < size <= 240000000:
                raise RuntimeError("Invalid capture size")
            if args.action == 'capture' and size != count * 4:
                raise RuntimeError('Captured size differs from requested sample count')
            args.destination.parent.mkdir(parents=True, exist_ok=True)
            actual, elapsed = console.download(remote, args.destination, size)
            if actual != hashes[0]:
                raise RuntimeError("Capture SHA256 does not match the Pluto file")
            print(json.dumps({"path": str(args.destination), "bytes": size,
                              "sha256": actual, "transfer_seconds": elapsed}))
    finally:
        console.close()


if __name__ == "__main__":
    main()

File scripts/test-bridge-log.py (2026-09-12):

"""Offline tests for passive logging; no hardware or network access."""
import contextlib
import importlib.util
import io
import json
from pathlib import Path
import tempfile
from types import SimpleNamespace
import unittest
from unittest.mock import patch

spec = importlib.util.spec_from_file_location('bridge_log', Path(__file__).with_name('bridge-log.py'))
logger = importlib.util.module_from_spec(spec)
spec.loader.exec_module(logger)


class FakeClient:
    # Deliberately provides no execute_service/movement API.
    def __init__(self, *args, **kwargs):
        self.disconnected = False
        self.fail = False

    async def connect(self, **kwargs):
        if self.fail:
            raise RuntimeError('connection failure')

    async def disconnect(self):
        self.disconnected = True

    def subscribe_logs(self, callback, **kwargs):
        if kwargs.get('dump_config') is not False:
            raise AssertionError('Full configuration must not be requested')
        callback(SimpleNamespace(message=b'RX synthetic'))
        callback(SimpleNamespace(message=b'RX second'))


class LoggerTests(unittest.IsolatedAsyncioTestCase):
    async def run_record(self, cap=4096, fail=False):
        with tempfile.TemporaryDirectory() as directory:
            path = Path(directory) / 'record.jsonl'
            client = FakeClient()
            client.fail = fail
            args = SimpleNamespace(host='example.invalid', expected_name='test',
                                   output=path, max_bytes=cap, seconds=0.01)
            output = io.StringIO()
            with patch.object(logger.aioesphomeapi, 'APIClient', return_value=client), contextlib.redirect_stdout(output):
                if fail:
                    with self.assertRaisesRegex(RuntimeError, 'connection failure'):
                        await logger.record(args)
                else:
                    await logger.record(args)
            self.assertTrue(client.disconnected)
            if not fail:
                reported = json.loads(output.getvalue().splitlines()[-1])
                self.assertEqual(path.stat().st_size, reported['bytes'])
            return path.read_text(encoding='utf-8'), output.getvalue()

    async def test_passive_timestamped_records(self):
        data, console = await self.run_record()
        records = [json.loads(line) for line in data.splitlines()]
        self.assertEqual([r['message'] for r in records], ['RX synthetic', 'RX second'])
        self.assertTrue(all(isinstance(r['host_time'], float) for r in records))
        self.assertNotIn('RX synthetic', console)

    async def test_byte_cap(self):
        data, console = await self.run_record(cap=1)
        self.assertEqual(data, '')
        self.assertTrue(json.loads(console.splitlines()[-1])['limit_reached'])

    async def test_connection_failure_disconnects(self):
        await self.run_record(fail=True)

    async def test_no_overwrite(self):
        with tempfile.TemporaryDirectory() as directory:
            path = Path(directory) / 'existing'
            path.write_text('original', encoding='utf-8')
            args = SimpleNamespace(host='example.invalid', expected_name='test', output=path)
            with patch.object(logger.aioesphomeapi, 'APIClient', FakeClient):
                with self.assertRaises(FileExistsError):
                    await logger.record(args)
            self.assertEqual(path.read_text(encoding='utf-8'), 'original')


if __name__ == '__main__':
    unittest.main()

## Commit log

2026-09-12 Add bounded ESP forwarding and camera-tested room controls
    [Print Base Final.step, Print Top Final.step]
2026-09-12 Record owner-confirmed enclosure fit
2026-09-13 Add ESPHome bridge diagnostics and Identify button (#2)
    * Add bridge diagnostics and onboard identification
    * Show expired learning windows before cached errors
2026-10-13 Release firmware 0.11.4-experimental
    Adds an optional Bluetooth advertisement scan pause during RF bursts, with a
    guarded build-copy compatibility hook for the pinned ESPHome 2026.4.1 tracker.
    Logs a bounded radio register snapshot when a transmission fails, and reads
    STATUS once more before declaring a failure so a stale pre-completion sample no
    longer causes a false abort. A false abort latched the relay fault and cancelled
    automatic repeats.
    Multi-target batches now give each target one contiguous block of rounds
    instead of interleaving targets in every round. Camera trials showed this alone
    does not prevent missed panels; the Norman HA integration now sends room
    sections as separate co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
2026-10-13 Widen room gap and record the bridge-paced trial result
    The inter-target gap is now 36 ticks (about 2 s). Camera trials showed the
    bridge-paced room still missing lounge panel 2 on its first pass with 0.6 s and
    2 s gaps, while separate single-target commands moved it every time. Norman HA
    0.5.1b2 sends room sections separately and uses the protocol 4 sequence fields
    only to confirm commands whose reply was lost; rf_room_command stays available
    but unused. Docs record the result; the cause is not established.
2026-10-13 Add a capped RF transmit power setting
    A config select (Minimum, Raised, High; restored across reboots) sets RF_SETUP
    power bits for every burst. High is the cap because the PA/LNA module gain is
    unmeasured and UK 2.4 GHz equipment is limited to 100 mW EIRP. Status reports
    tx_power_level. Firmware 0.12.2-experimental, installed on all three bridges.
